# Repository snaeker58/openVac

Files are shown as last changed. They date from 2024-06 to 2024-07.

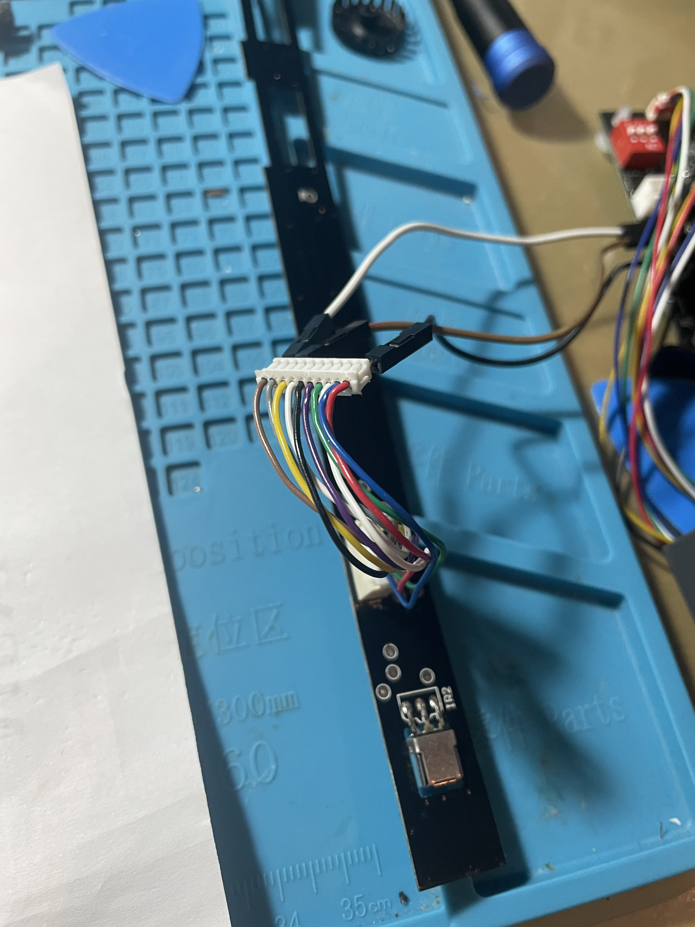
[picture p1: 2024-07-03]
Sessions/v0 Sessions (Sessions 1 - 13)/Session 12/img_build2.jpeg

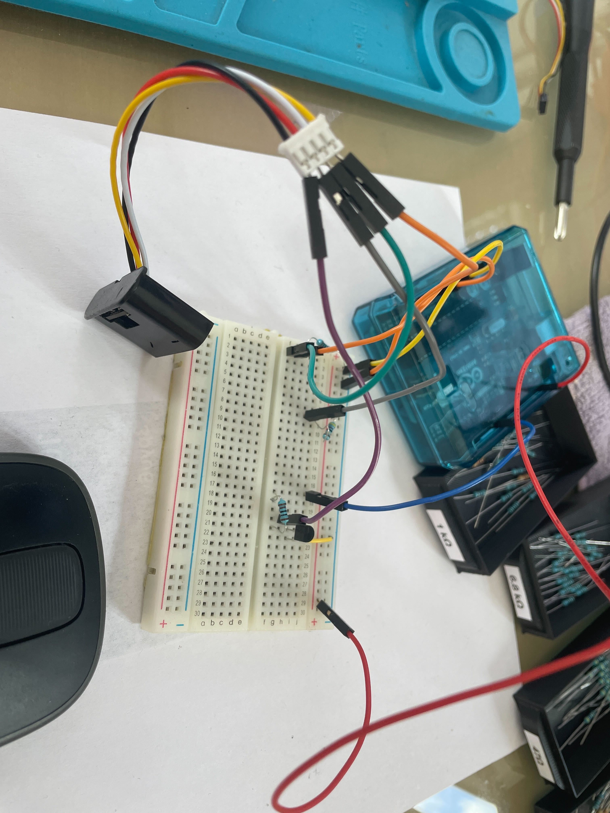
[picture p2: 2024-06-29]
Sessions/v0 Sessions (Sessions 1 - 13)/Session 2/img-build.jpg

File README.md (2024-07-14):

# OpenVac Project

The goal of OpenVac is to create a new open-source control board for my braindead eufy RoboVac 11.

## General Timeline

### Concept v0

#### Finished

##### Motor Drive Circuit
- motor driver / H-bridge design

##### Brush Control
- drive circuits for all cleaning brushes

##### Vacuum
- understanding pinout

##### Basic Sensing
- understanding the various sensors
- reverse engineering the main sensor array
- make edge sensors functional
  
---

### Movement Phase v0.1

#### In Progress

##### Basic Movement
- steering and acceleration

##### Movement PCB
- motor drive circuit
- side brush control circuit
- main brush control circuit
- PWM vacuum 
  
---
### Future Phases...

#### Further Down the Line

##### Determine Microprocessor
- Based on GPIO and analog as well as performance requirements

##### Integrate Microprocessor
- Hardware integration of all support circuits required by the microprocessor and connection to all previous systems

#### Far Future

##### Navigational Software
- Software to allow autonomous cleaning

##### User Interface
- Interface to allow more precise control

### Estimated Time
2 years to infinity

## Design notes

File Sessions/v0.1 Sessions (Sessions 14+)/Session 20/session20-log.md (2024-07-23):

# Building an Open Source Robot Vacuum Based on the Eufy RoboVac 11 - Session 20

### Progress Update

- **Cost Optimization**
  - Modified the board to fit within a 100mm by 100mm space
  - Applied for a $100 PCB production grant to finance PCBs across all phases
  - Reduced the board cost from €40 to €4

### Next Steps

- **Grant Utilization**
  - Plan to use the grant to finance the production of PCBs in all phases

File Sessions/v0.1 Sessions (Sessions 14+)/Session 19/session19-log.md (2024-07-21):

# Building an Open Source Robot Vacuum Based on the Eufy RoboVac 11 - Session 19

### Progress Update

- **Board Completion**
  - Finished the PCB design
  - Design Rule Check (DRC) completed successfully
  - Current board cost is €44 due to its size

### Next Steps

- **Cost Optimization**
  - Create a second, cost-optimized version of the PCB in the next session

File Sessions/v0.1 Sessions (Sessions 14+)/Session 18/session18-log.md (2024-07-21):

# Building an Open Source Robot Vacuum Based on the Eufy RoboVac 11 - Session 18

### Progress Update

- **Component Placement and Routing**
  - Placed all components in their designated spots on the board
  - Began the routing process

### Next Steps

- **Board Completion and Verification**
  - Finish routing the board
  - Conduct final verification before ordering the PCB

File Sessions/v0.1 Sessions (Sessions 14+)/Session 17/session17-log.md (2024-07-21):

# Building an Open Source Robot Vacuum Based on the Eufy RoboVac 11 - Session 17

### Progress Update

- **Motor Drive Transfer**
  - Transferred the motor drive to the schematic and PCB
  - Began working on the PCB layout

### Next Steps

- **Layout Completion**
  - Continue and complete the PCB layout in the next session

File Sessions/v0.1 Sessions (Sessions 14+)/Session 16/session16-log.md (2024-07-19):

# Building an Open Source Robot Vacuum Based on the Eufy RoboVac 11 - Session 16

### Progress Update

- **Motor Encoder Success**
  - Repeated previous attempts to integrate the motor encoder, achieving successful operation
  - Determined the gearing ratio from encoder to wheel is either 1:40 or 1:44

### Next Steps

- **Board Transfer and Finalization**
  - Transfer the working motor encoder setup to the PCB
  - Begin finalizing the board design in the next session

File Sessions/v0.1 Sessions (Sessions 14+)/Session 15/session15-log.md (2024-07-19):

# Building an Open Source Robot Vacuum Based on the Eufy RoboVac 11 - Session 15

### Progress Update

- **Vacuum Transfer and PWM Testing**
  - Transferred the vacuum system to the new setup
  - Spent significant time testing the PWM to ensure proper functionality
  - Encountered and addressed some strange behavior when changing the PWM signal

- **Cable Modification**
  - Modified the cable to fit JST Ph connectors
  - Noted that these connectors may need upgrading due to the close Amp limits for JST Phs

### Next Steps

- **Wheel Encoders**
  - Tackle the integration of wheel encoders, anticipating potential difficulties
  - Prepare for the possibility of replacing wheel encoders with hall effect sensors if necessary

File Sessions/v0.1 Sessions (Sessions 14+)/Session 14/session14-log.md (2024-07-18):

# Building an Open Source Robot Vacuum Based on the Eufy RoboVac 11 - Session 14

### Progress Update

- **First Viable PCB Design**
  - Started working on the first viable PCB design
  - The design is simple, including only necessary components for easy testing with an Arduino Uno
  - Transferred all brush motor controls to the new PCB design
  - Spent considerable time matching the holes and odd shape of the original PCB to ensure the new one fits as a drop-in replacement

### Next Steps

- **PCB Design Finalization**
  - Finalize the PCB design, ensuring all necessary components and fittings are accurate
  - Prepare for initial testing with the Arduino Uno once the PCB is ready

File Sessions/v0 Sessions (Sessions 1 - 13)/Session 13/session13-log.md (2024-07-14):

# Building an Open Source Robot Vacuum Based on the Eufy RoboVac 11 - Session 13

### Progress Update

- **Bumper Array Transfer**
  - Transferred the bumper array schematics to the KiCad project

- **Development Process Restructure**
  - Restructured the development process from phase v0 to v0.1
  - This restructuring does not include a specific hardware or software milestone
  - Most previous work remains intact

### Next Steps

- **Motor Encoders**
  - Implement motor encoders to enable non-autonomous movement in the next session

- **No-Sensor PCB Prototype**
  - Create the first no-sensor PCB prototype to test movement following the implementation of motor encoders

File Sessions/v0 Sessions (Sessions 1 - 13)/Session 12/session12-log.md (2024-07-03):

# Building an Open Source Robot Vacuum Based on the Eufy RoboVac 11 - Session 13

### Progress Update

- **Functionality Testing**
  - Decided to test the functionality of the main sensor array instead of transferring schematics to KiCad
  - Verified the accuracy of the hand-drawn schematic
  - Encountered confusion regarding the original robot's implementation
  - Powered the IR LEDs from the 12V rail

### Next Steps

- **Main Sensor Array in KiCad**
  - Add the main sensor array to KiCad in upcoming sessions
- **Infrared Sensing Code**
  - Modify and write code for infrared sensing
- **Research**
  - Conduct research into pulsed IR distance sensing

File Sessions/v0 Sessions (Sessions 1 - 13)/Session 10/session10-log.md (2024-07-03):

# Building an Open Source Robot Vacuum Based on the Eufy RoboVac 11 - Session 10

### Progress Update

- **Reverse Engineering Sensors**
  - Spent the session reverse engineering the main sensors in the bumper bar
  - Understood the actual bumpers (which are also IR) and the side IR sensor
  - Encountered a complex IR LED array in the main bumper bar with components labeled Q? resembling transistors, LEDs, or receivers
  - Progress was slow due to time spent removing foam from the PCB

### Next Steps

- **Clarifying Sensor Components**
  - Continue investigating the components in the main bumper bar
  - Aim to clear up confusion regarding the Q-labeled components in the next session

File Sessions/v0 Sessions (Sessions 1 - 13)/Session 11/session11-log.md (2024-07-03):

# Building an Open Source Robot Vacuum Based on the Eufy RoboVac 11 - Session 11

### Progress Update

- **Main Sensor Array Schematics**
  - Created the first schematics of the main sensor array
  - Identified two LED arrays and three possible SMD sensor arrays
  - Also identified two larger sensor arrays

### Next Steps

- **KiCad File Transfer**
  - Transfer the schematics to a KiCad file in the next session

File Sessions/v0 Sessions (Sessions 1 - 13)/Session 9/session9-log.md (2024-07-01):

# Building an Open Source Robot Vacuum Based on the Eufy RoboVac 11 - Session 9

### Progress Update

- **Cleaning Brushes Motors**
  - Finished wiring up all the remaining cleaning brushes motors
  - Wiring was straightforward and simple

- **PWM Fan**
  - PWM fan was already pinned out and includes its own PWM controller
  - Only requires a PWM signal for operation
  - Plan to write the prototype code for the PWM fan in the next session

### Next Steps

- **Major Sensing System**
  - With the PWM fan prototype code pending, the major sensing system is the last component to address before completing the first prototype hardware revision

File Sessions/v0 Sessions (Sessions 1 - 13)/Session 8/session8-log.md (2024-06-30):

# Building an Open Source Robot Vacuum Based on the Eufy RoboVac 11 - Session 8
### Progress Update

- **Prototype Sketch**
  - Wrote a prototype sketch that worked successfully
  - Leveraged knowledge of writing libraries, avoiding the need for refactoring
  - Writing and implementing the library in a simpler sketch was seamless

- **EdgeSens Library Revision**
  - Revised the EdgeSens library
  - Removed unnecessary serial begin in the library implementation

### Next Steps

- **Testing with Actual Motors**
  - Awaiting orders to arrive for testing with the actual motors
- **Circuit Design**
  - Continue designing circuits for the brushes, which shouldn't be too difficult

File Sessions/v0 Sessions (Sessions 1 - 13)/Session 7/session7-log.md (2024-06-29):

# Building an Open Source Robot Vacuum Based on the Eufy RoboVac 11 - Session 7

### Progress Update

- **H-Bridge Development**
  - Built the "final" H-Bridge
  - Found a few issues with MOSFETs orientation in the schematics
  - The build took most of the hour, resulting in little progress otherwise

- **Next Steps**
  - Now that the build works, I can start writing the code to digitally control it

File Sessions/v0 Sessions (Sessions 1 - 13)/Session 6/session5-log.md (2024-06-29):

# Building an Open Source Robot Vacuum Based on the Eufy RoboVac 11 - Session 6

### Progress Update

- This session, I could finally test my written library
  - Required a few minor fixes and a `keywords.txt`
  - Now fully working and much simpler in code than the previous prototype setup

- Next Steps
  - Write a prototype to drive the motors through the H-Bridge with the Arduino Uno R3

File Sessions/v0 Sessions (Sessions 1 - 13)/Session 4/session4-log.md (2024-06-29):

# Building an Open Source Robot Vacuum Based on the Eufy RoboVac 11 - Session 4

### Progress Update

- **H-Bridge Motor Driver**
  - Drive circuit is now functional
  - Overhauled the schematic into a proper hierarchical structure

- **Upcoming Tasks**
  - This weekend, drive motor and edge sensor circuits should enter the validation phase
  - After validation, start working on cleaning motors and positional IR sensing
  - Filtering and other non-functional features will likely need to be added

- **Future Plans**
  - After designing and validating all individual circuits, the general architecture of the platform can be determined (e.g., ESP32-S3-Wroom-1U, Arduino Nano 33 IoT)
  - Determining the platform architecture is still far in the future as the requirements are still unclear

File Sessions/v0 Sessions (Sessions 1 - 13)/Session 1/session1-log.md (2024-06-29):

# Building an Open Source Robot Vacuum Based on the Eufy RoboVac 11 - Session 1

### Progress Update

- **Designed First Revision of the H-Bridge for the Main Drive System**
  - Encountered issues with the transistors controlling the P-Channel MOSFETs
  - Breadboard testing seems to have ended in success (TBD if it can be implemented in its current form into the H-Bridge)

- **Main Drive Motors**
  - Successfully pinned our main drive motors
  - Killed encoder sensor in the process, but have replacements on hand

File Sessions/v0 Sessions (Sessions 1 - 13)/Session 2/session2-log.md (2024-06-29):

# Building an Open Source Robot Vacuum Based on the Eufy RoboVac 11 - Session 2

### Progress Update

- **Drive Circuit**
  - Due to pending part orders, the drive circuit had to be put on hold
  - Drive circuit development should continue this week when deliveries arrive

- **Infrared Sensing**
  - Started on the infrared sensing
  - Circuit is complete and tested
  - In the next session, I will work on the code

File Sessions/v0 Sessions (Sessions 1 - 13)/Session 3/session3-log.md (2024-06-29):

# Building an Open Source Robot Vacuum Based on the Eufy RoboVac 11 - Session 3

### Progress Update

- **Code Development / Refinement for the Infrared Sensing Mechanism**
  - Basic code is finished
  - The sensor works and has been set to clamp for an edge sensor application
  - If the robot moves over a ledge, it will trip

- **Next Steps**
  - Convert the code into a library
  - Once the drive system is finished, move all systems to a prototype board and perform a test drive
  - This should enable some real-world testing of the edge sensor mechanism

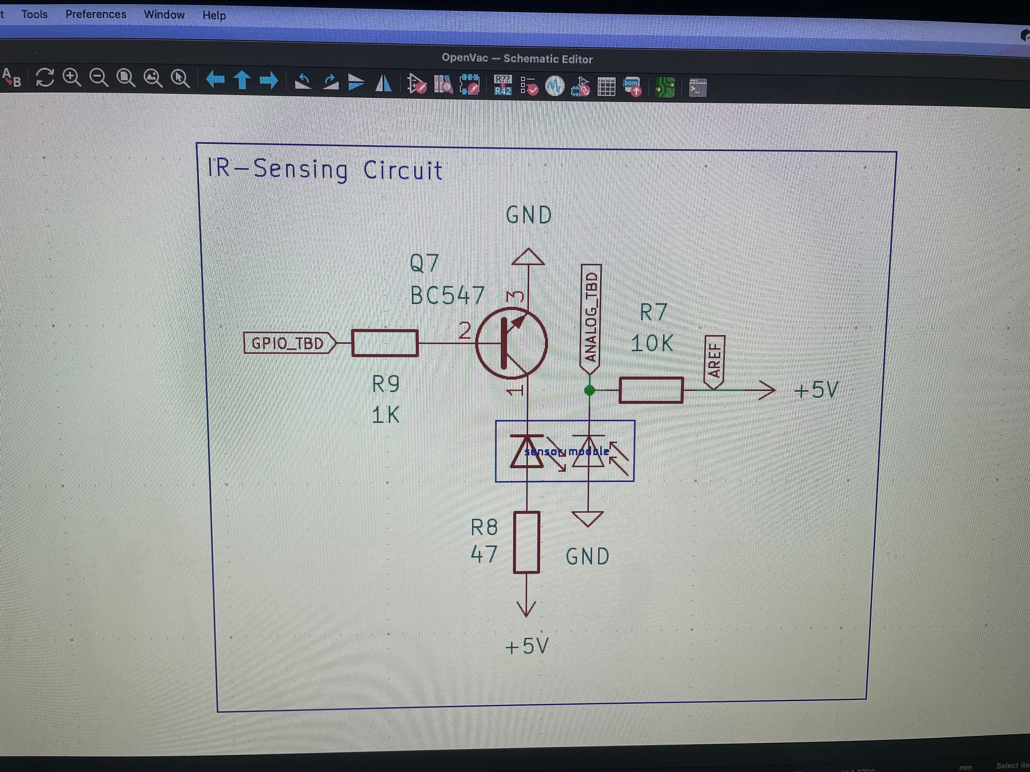
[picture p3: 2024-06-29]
Sessions/v0 Sessions (Sessions 1 - 13)/Session 2/img-schematic.jpg

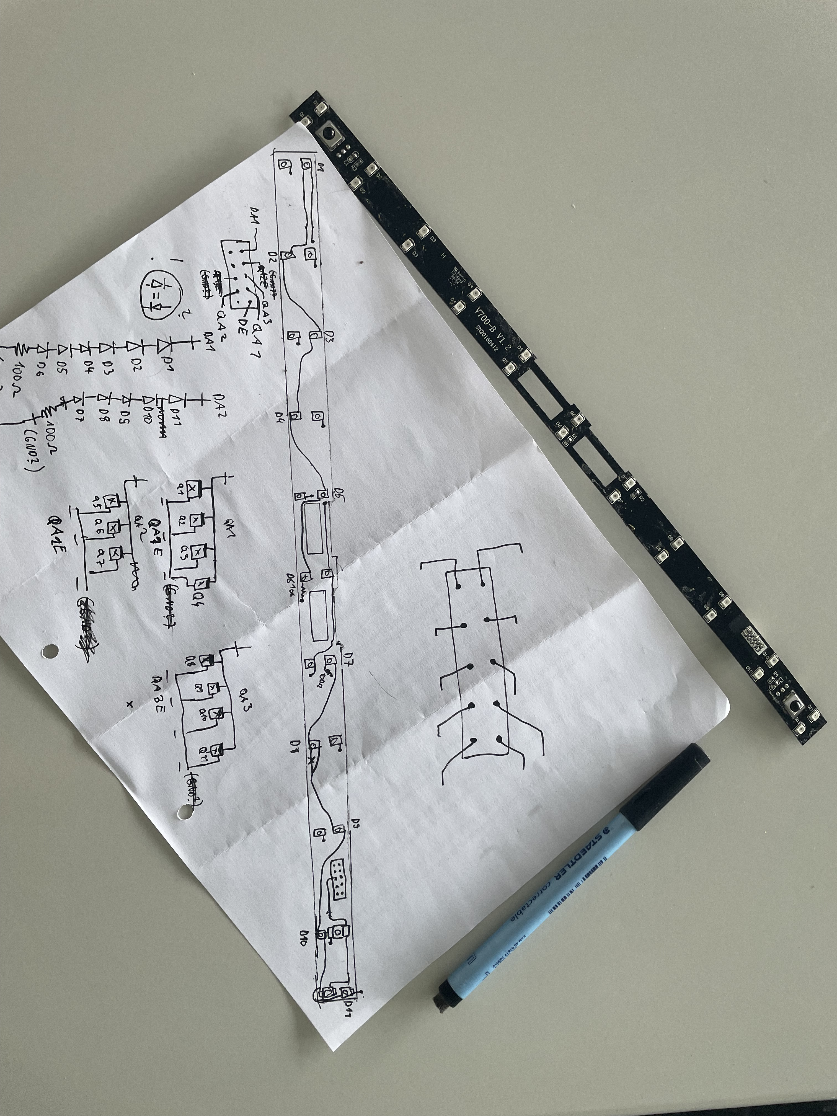
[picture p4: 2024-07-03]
Sessions/v0 Sessions (Sessions 1 - 13)/Session 11/img_schematic.jpeg

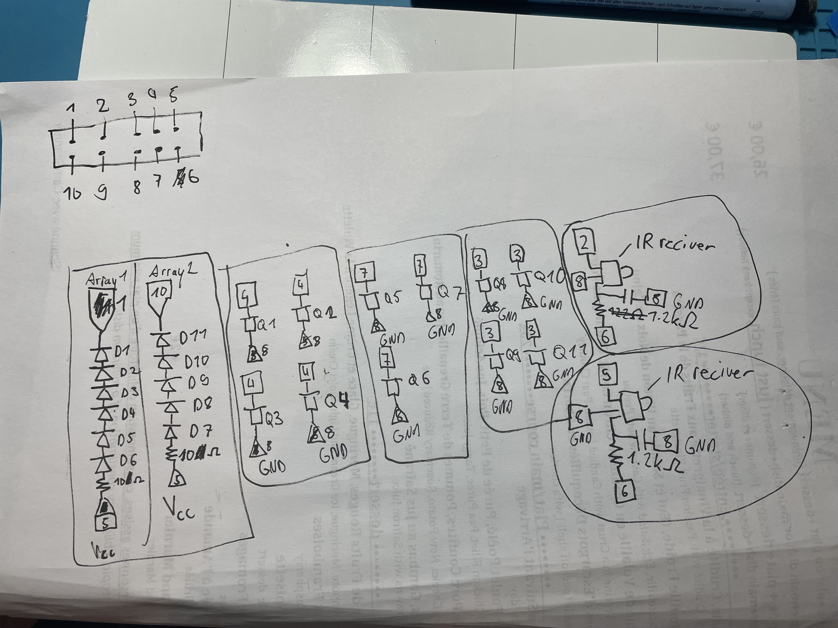
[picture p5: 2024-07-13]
Sessions/v0 Sessions (Sessions 1 - 13)/Session 12/img_schematic.jpeg

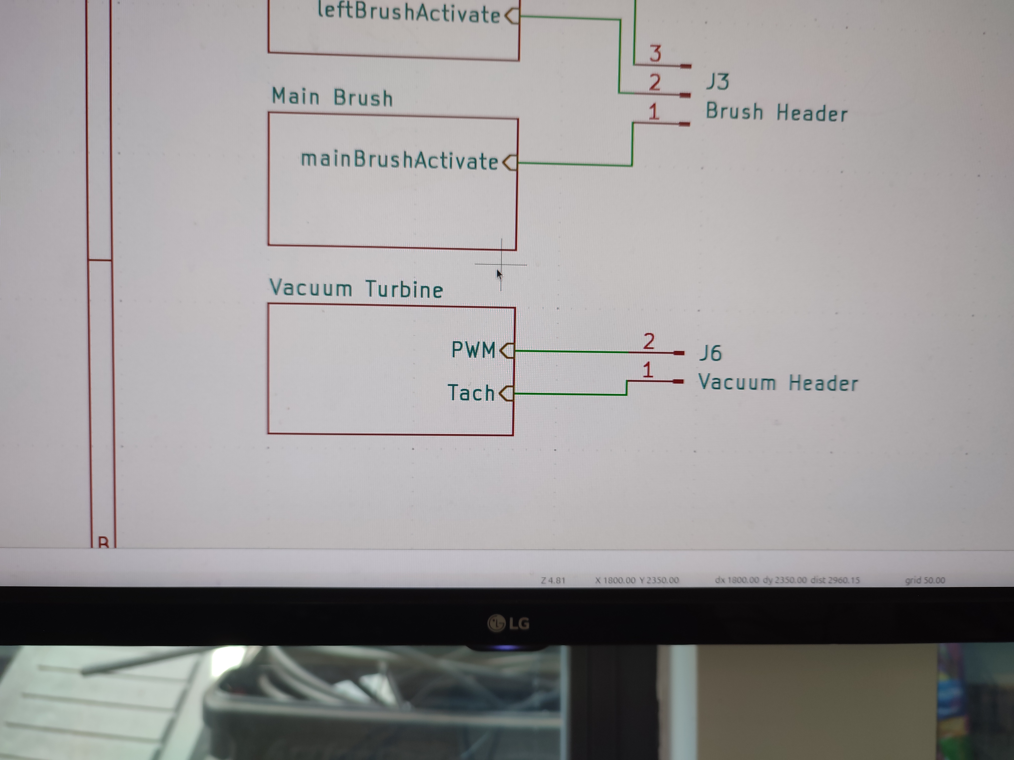
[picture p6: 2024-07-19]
Sessions/v0.1 Sessions (Sessions 14+)/Session 15/img_schematic.jpg

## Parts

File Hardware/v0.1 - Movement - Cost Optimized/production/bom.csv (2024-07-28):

Designator | Footprint | Quantity | Value | LCSC Part #
C1, C2 | CP_Radial_D4.0mm_P1.50mm | 2 | 0.1uF
J1 | JST_PH_B2B-PH-K_1x02_P2.00mm_Vertical | 1 | Brush Motor 2 (right)
J2 | JST_PH_B2B-PH-K_1x02_P2.00mm_Vertical | 1 | Brush Motor 1 (left)
J3 | JST_PH_B3B-PH-K_1x03_P2.00mm_Vertical | 1 | Brush Header (control)
J4 | JST_PH_B2B-PH-K_1x02_P2.00mm_Vertical | 1 | Brush Motor Main
J5 | JST_PH_B4B-PH-K_1x04_P2.00mm_Vertical | 1 | Vacuum
J6 | JST_PH_B2B-PH-K_1x02_P2.00mm_Vertical | 1 | Vacuum Header (control)
J7 | JST_PH_B6B-PH-K_1x06_P2.00mm_Vertical | 1 | Motor (left)
J8 | JST_PH_B6B-PH-K_1x06_P2.00mm_Vertical | 1 | Motor (right)
J9 | JST_PH_B6B-PH-K_1x06_P2.00mm_Vertical | 1 | Motor Header (control)
Q1, Q10, Q12, Q13, Q15, Q2, Q3, Q4, Q6, Q7, Q9 | TO-220-3_Vertical | 11 | IRF540N
Q11, Q14, Q5, Q8 | TO-220-3_Vertical | 4 | IRF9540N
R1, R10, R12, R13, R14, R17, R18, R19, R2, R3, R5, R6, R7, R8, R9 | R_Axial_DIN0207_L6.3mm_D2.5mm_P10.16mm_Horizontal | 15 | 10k
R11, R15 | R_Axial_DIN0207_L6.3mm_D2.5mm_P10.16mm_Horizontal | 2 | 10
R16, R4 | R_Axial_DIN0207_L6.3mm_D2.5mm_P10.16mm_Horizontal | 2 | 5.1k

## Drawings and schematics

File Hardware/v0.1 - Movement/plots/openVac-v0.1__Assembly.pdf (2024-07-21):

A

A

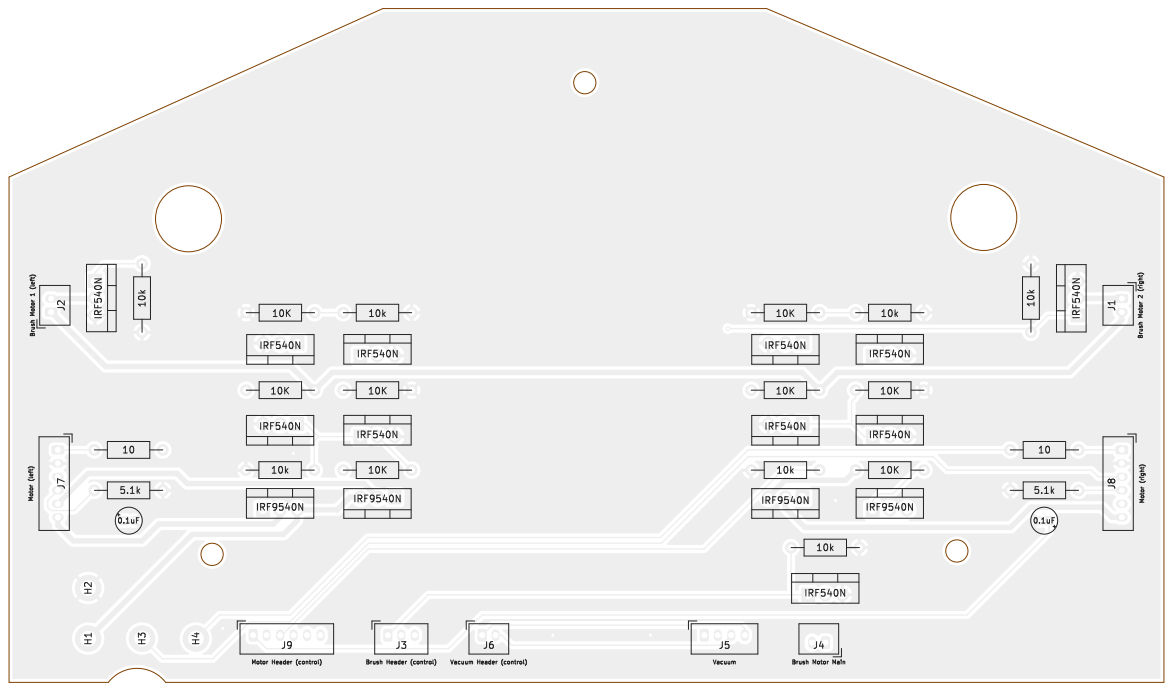
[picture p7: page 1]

Id: 1/1 Title: File: openVac-v0.1.kicad_pcb Sheet:

J6 J7 1 | 2 | 3 | 4 | 5 | 6

A

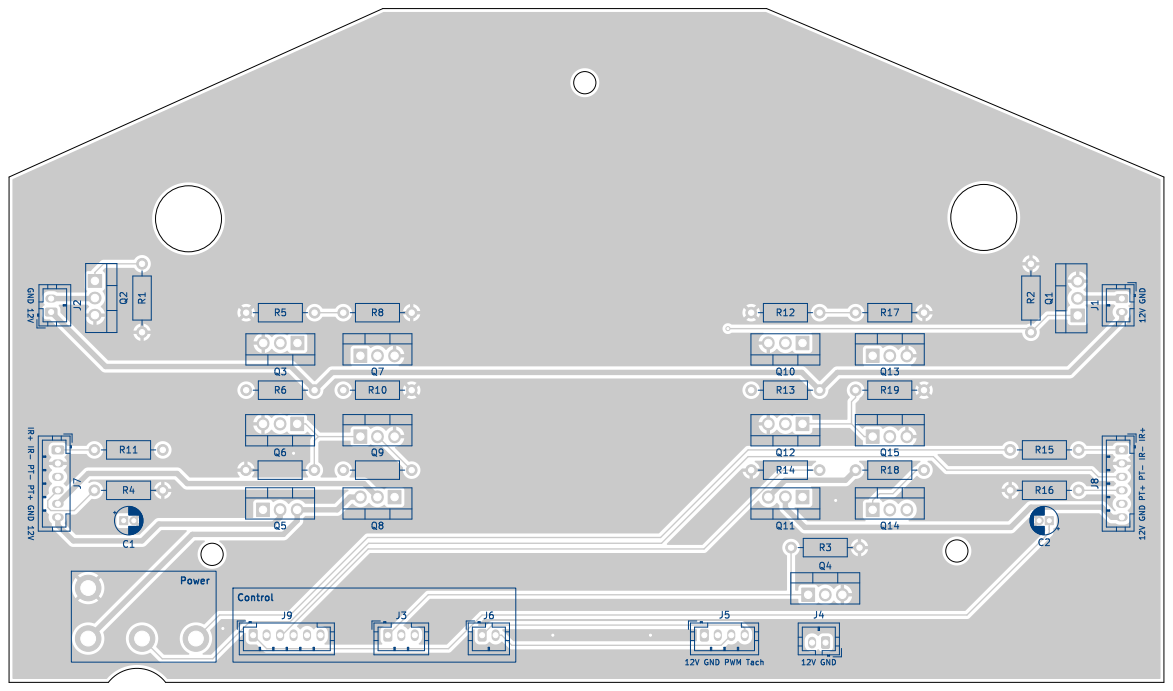
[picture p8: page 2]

12V GNDGND 12V 12V GND PT+ PT- IR- IR+IR+ IR- PT- PT+ GND 12V

Id: 1/1 Title: File: openVac-v0.1.kicad_pcb Sheet:

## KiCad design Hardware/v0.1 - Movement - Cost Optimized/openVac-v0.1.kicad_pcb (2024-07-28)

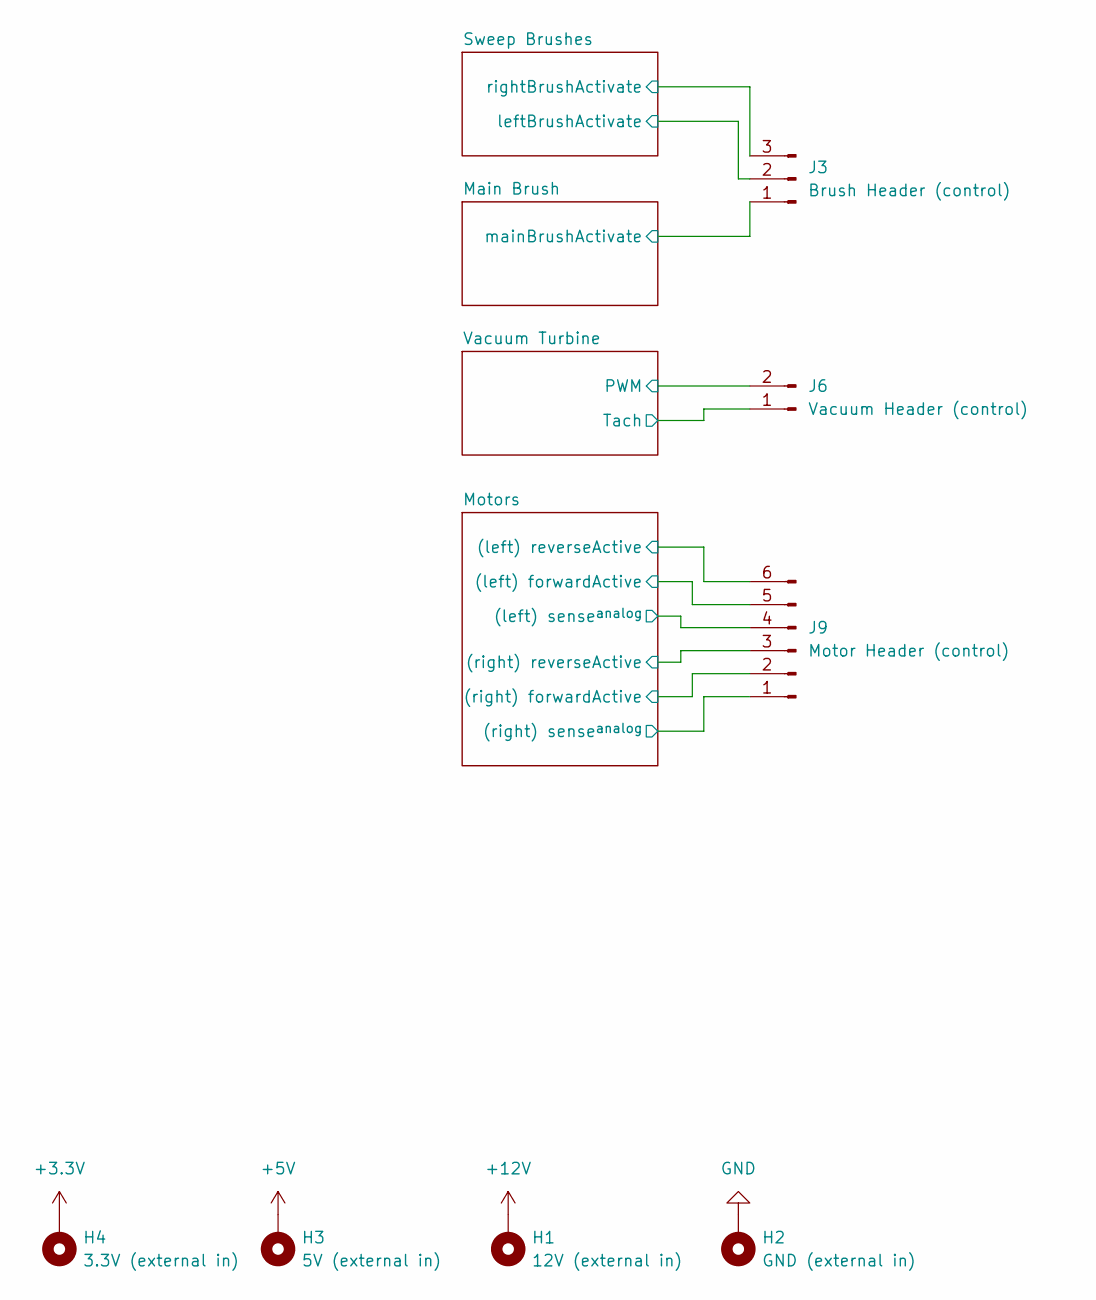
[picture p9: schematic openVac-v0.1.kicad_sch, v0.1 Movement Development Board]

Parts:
H1: 12V (external in); MountingHole_2.2mm_M2_DIN965_Pad
H2: GND (external in); MountingHole_2.2mm_M2_DIN965_Pad
H3: 5V (external in); MountingHole_2.2mm_M2_DIN965_Pad
H4: 3.3V (external in); MountingHole_2.2mm_M2_DIN965_Pad
J3: Brush Header (control); JST_PH_B3B-PH-K_1x03_P2.00mm_Vertical
J6: Vacuum Header (control); JST_PH_B2B-PH-K_1x02_P2.00mm_Vertical
J9: Motor Header (control); JST_PH_B6B-PH-K_1x06_P2.00mm_Vertical

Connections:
+3.3V: H4.1; also elsewhere on the board
+5V: H3.1; also elsewhere on the board
+12V: H1.1; also elsewhere on the board
/Main Brush/mainBrushActivate: J3.1; also elsewhere on the board
/Motors/(left) forwardActive: J9.5; also elsewhere on the board
/Motors/(left) reverseActive: J9.6; also elsewhere on the board
/Motors/(left) sense^{analog}: J9.4; also elsewhere on the board
/Motors/(right) forwardActive: J9.2; also elsewhere on the board
/Motors/(right) reverseActive: J9.3; also elsewhere on the board
/Motors/(right) sense^{analog}: J9.1; also elsewhere on the board
/Sweep Brushes/leftBrushActivate: J3.2; also elsewhere on the board
/Sweep Brushes/rightBrushActivate: J3.3; also elsewhere on the board
/Vacuum Turbine/PWM: J6.2; also elsewhere on the board
/Vacuum Turbine/Tach: J6.1; also elsewhere on the board
GND: H2.1; also elsewhere on the board

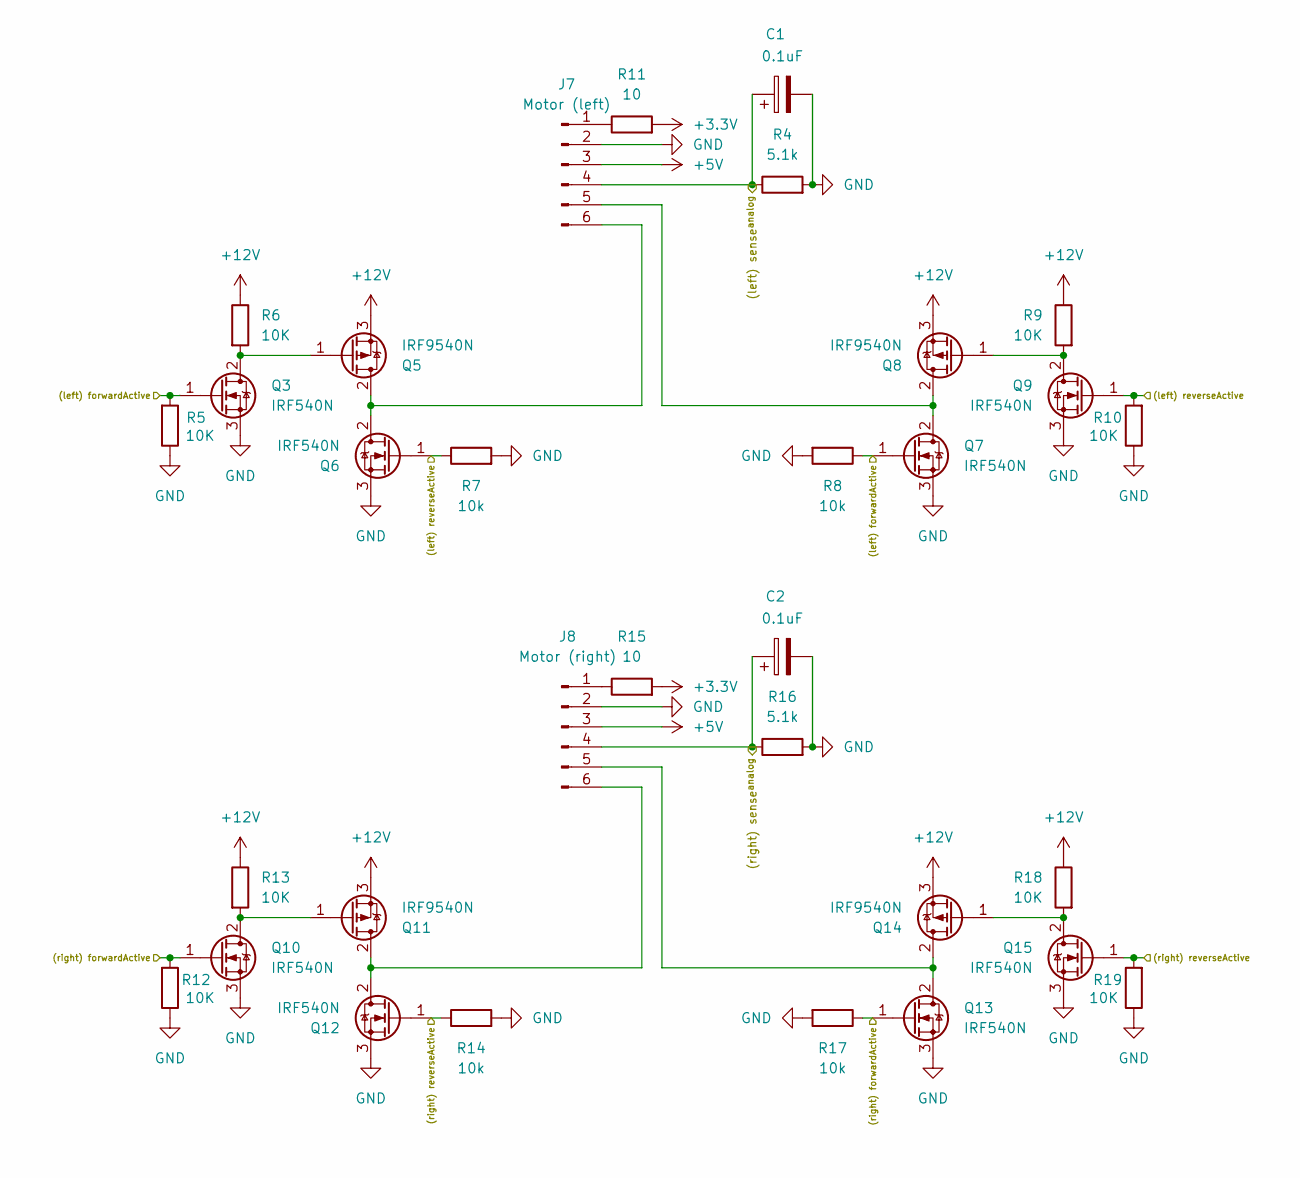
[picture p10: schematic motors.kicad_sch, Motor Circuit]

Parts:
C1, C2: 0.1uF; CP_Radial_D4.0mm_P1.50mm
J7: Motor (left); JST_PH_B6B-PH-K_1x06_P2.00mm_Vertical
J8: Motor (right); JST_PH_B6B-PH-K_1x06_P2.00mm_Vertical
Q3, Q6, Q7, Q9, Q10, Q12, Q13, Q15: IRF540N; TO-220-3_Vertical
Q5, Q8, Q11, Q14: IRF9540N; TO-220-3_Vertical
R4, R16: 5.1k; R_Axial_DIN0207_L6.3mm_D2.5mm_P10.16mm_Horizontal
R5, R6, R9, R10, R12, R13, R18, R19: 10K; R_Axial_DIN0207_L6.3mm_D2.5mm_P10.16mm_Horizontal
R7, R8, R14, R17: 10k; R_Axial_DIN0207_L6.3mm_D2.5mm_P10.16mm_Horizontal
R11, R15: 10; R_Axial_DIN0207_L6.3mm_D2.5mm_P10.16mm_Horizontal

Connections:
+3.3V: R11.2, R15.2; also elsewhere on the board
+5V: J7.3, J8.3; also elsewhere on the board
+12V: Q5.3 (S), Q8.3 (S), Q11.3 (S), Q14.3 (S), R6.1, R9.1, R13.1, R18.1; also elsewhere on the board
/Motors/(left) forwardActive: Q3.1 (G), Q7.1 (G), R5.2, R8.1; also elsewhere on the board
/Motors/(left) reverseActive: Q6.1 (G), Q9.1 (G), R7.1, R10.2; also elsewhere on the board
/Motors/(left) sense^{analog}: C1.1, J7.4, R4.1; also elsewhere on the board
/Motors/(right) forwardActive: Q10.1 (G), Q13.1 (G), R12.2, R17.1; also elsewhere on the board
/Motors/(right) reverseActive: Q12.1 (G), Q15.1 (G), R14.1, R19.2; also elsewhere on the board
/Motors/(right) sense^{analog}: C2.1, J8.4, R16.1; also elsewhere on the board
GND: C1.2, C2.2, J7.2, J8.2, Q3.3 (S), Q6.3 (S), Q7.3 (S), Q9.3 (S), Q10.3 (S), Q12.3 (S), Q13.3 (S), Q15.3 (S), R4.2, R5.1, R7.2, R8.2, R10.1, R12.1, R14.2, R16.2, R17.2, R19.1; also elsewhere on the board
unnamed: J7.1, R11.1
unnamed: J7.5, Q7.2 (D), Q8.2 (D)
unnamed: J7.6, Q5.2 (D), Q6.2 (D)
unnamed: J8.1, R15.1
unnamed: J8.5, Q13.2 (D), Q14.2 (D)
unnamed: J8.6, Q11.2 (D), Q12.2 (D)
unnamed: Q3.2 (D), Q5.1 (G), R6.2
unnamed: Q8.1 (G), Q9.2 (D), R9.2
unnamed: Q10.2 (D), Q11.1 (G), R13.2
unnamed: Q14.1 (G), Q15.2 (D), R18.2

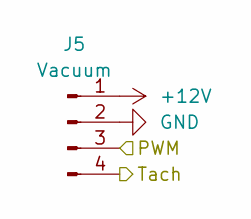
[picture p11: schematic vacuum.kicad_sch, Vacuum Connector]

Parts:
J5: Vacuum; JST_PH_B4B-PH-K_1x04_P2.00mm_Vertical

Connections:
+12V: J5.1; also elsewhere on the board
/Vacuum Turbine/PWM: J5.3; also elsewhere on the board
/Vacuum Turbine/Tach: J5.4; also elsewhere on the board
GND: J5.2; also elsewhere on the board

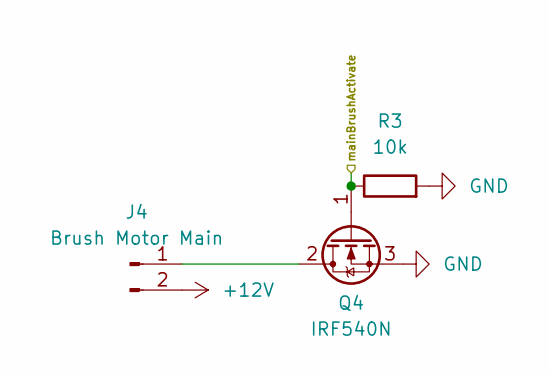
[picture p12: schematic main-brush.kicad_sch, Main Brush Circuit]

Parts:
J4: Brush Motor Main; JST_PH_B2B-PH-K_1x02_P2.00mm_Vertical
Q4: IRF540N; TO-220-3_Vertical
R3: 10k; R_Axial_DIN0207_L6.3mm_D2.5mm_P10.16mm_Horizontal

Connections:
+12V: J4.2; also elsewhere on the board
/Main Brush/mainBrushActivate: Q4.1 (G), R3.1; also elsewhere on the board
GND: Q4.3 (S), R3.2; also elsewhere on the board
unnamed: J4.1, Q4.2 (D)

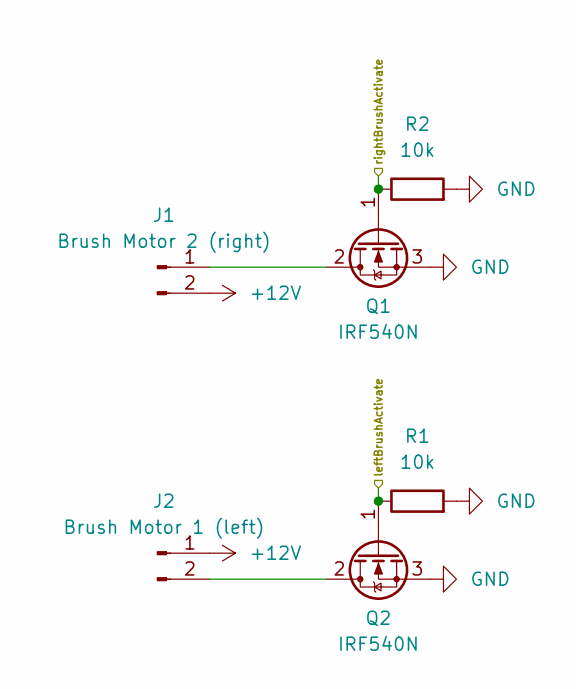
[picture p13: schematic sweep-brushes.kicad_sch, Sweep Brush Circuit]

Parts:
J1: Brush Motor 2 (right); JST_PH_B2B-PH-K_1x02_P2.00mm_Vertical
J2: Brush Motor 1 (left); JST_PH_B2B-PH-K_1x02_P2.00mm_Vertical
Q1, Q2: IRF540N; TO-220-3_Vertical
R1, R2: 10k; R_Axial_DIN0207_L6.3mm_D2.5mm_P10.16mm_Horizontal

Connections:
+12V: J1.2, J2.1; also elsewhere on the board
/Sweep Brushes/leftBrushActivate: Q2.1 (G), R1.1; also elsewhere on the board
/Sweep Brushes/rightBrushActivate: Q1.1 (G), R2.1; also elsewhere on the board
GND: Q1.3 (S), Q2.3 (S), R1.2, R2.2; also elsewhere on the board
unnamed: J1.1, Q1.2 (D)
unnamed: J2.2, Q2.2 (D)

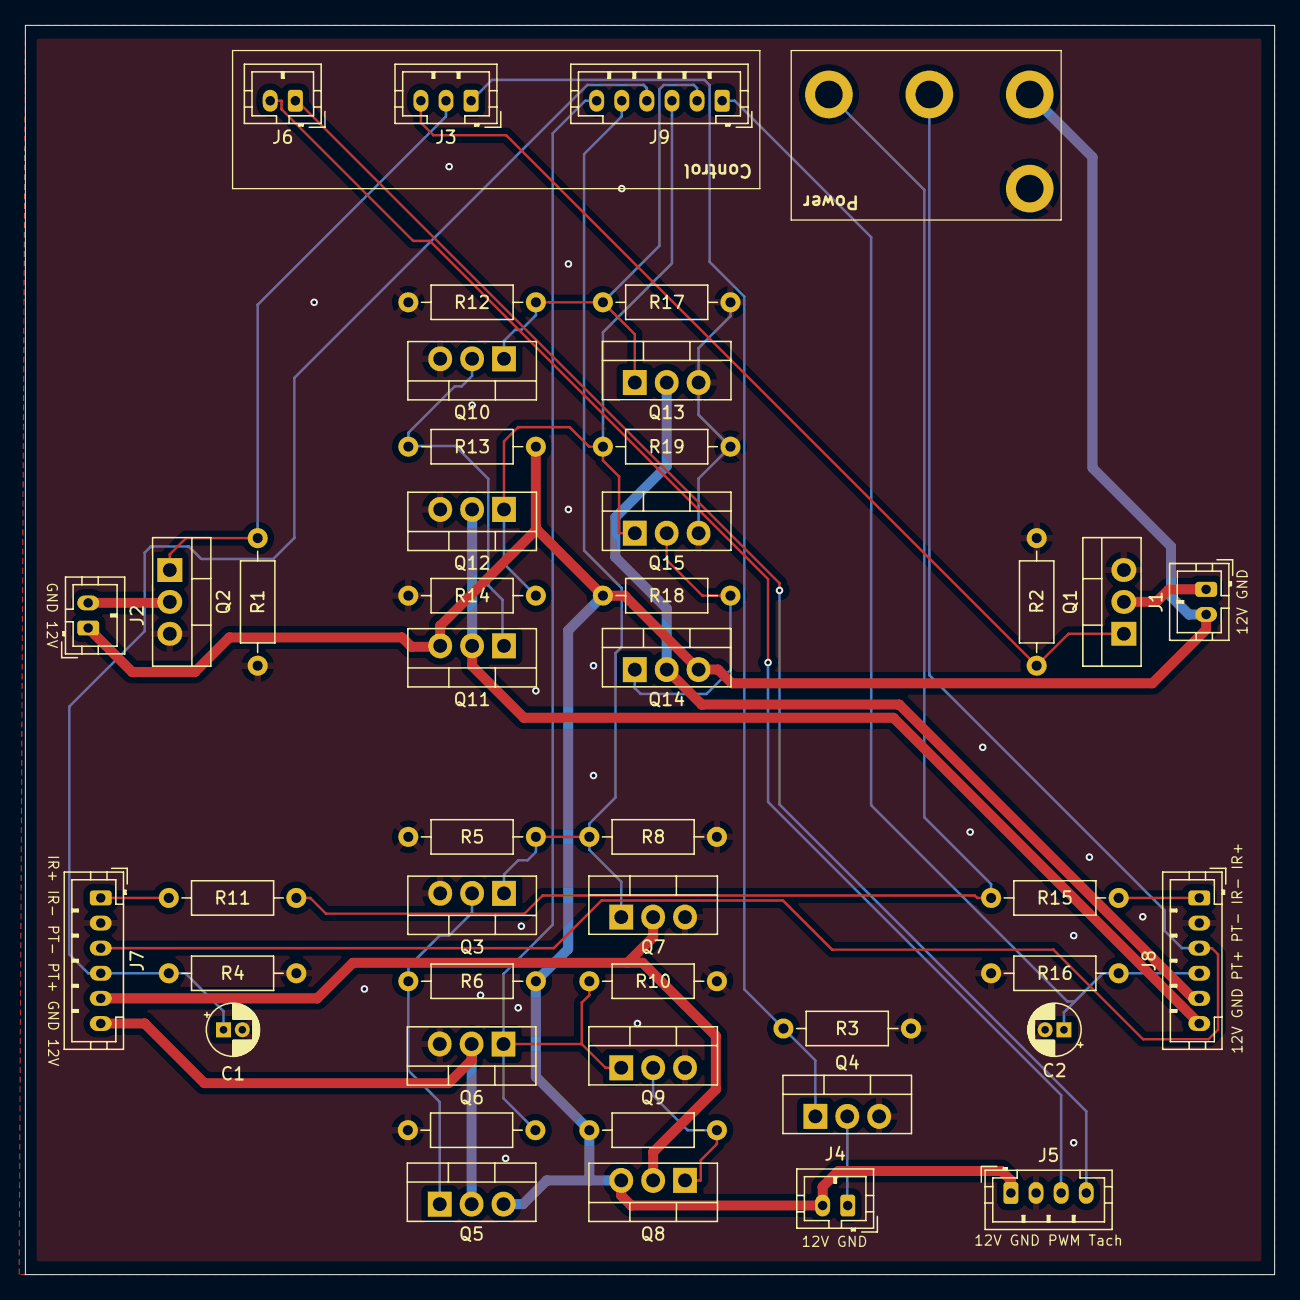
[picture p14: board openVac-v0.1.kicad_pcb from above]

Board: 2 copper layers, 99.5 x 99.5 mm, 49 parts (0 on the bottom side), 28 nets.

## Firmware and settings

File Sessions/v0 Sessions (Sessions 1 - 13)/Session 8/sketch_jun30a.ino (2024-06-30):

#include <MotorDrive.h>

const int drivePin1 = 2;
const int drivePin2 = 3;
MotorDrive motor(drivePin1, drivePin2);

void setup() {
  for (int i = 0; i < 20; i++) {
      motor.forward();
    delay(100);
    motor.backward();
    delay(100);
    motor.forward();
    delay(100);
    motor.backward();
    delay(100);
    }
    motor.stop();
}

void loop() {}

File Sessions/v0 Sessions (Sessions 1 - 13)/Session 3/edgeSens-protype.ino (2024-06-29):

const int irControlPin =  5;  
const int irReceiverPin = A0;
unsigned long ambientSignal, activeSignal; 
unsigned int proximity;
unsigned int normalizedProximity;
bool edgeTrip;

void setup()   {
  Serial.begin(9600);
  analogReference(EXTERNAL);
  pinMode(irControlPin, OUTPUT);
}

void loop(){
  edgeTrip = false;
  ambientSignal = 0;
  activeSignal = 0;
  
  for(int i=0; i<25; i++){
    ambientSignal += analogRead(irReceiverPin);
    delayMicroseconds(500);
  }
  ambientSignal /= 25;

  digitalWrite(irControlPin, HIGH);
  for(int i=0; i<25; i++){
    activeSignal += analogRead(irReceiverPin);
    delayMicroseconds(500);
  }
  activeSignal /= 50;
  
  proximity = ambientSignal - activeSignal;
  normalizedProximity = constrain(proximity, 600, 900);
  if (normalizedProximity == 600) {
    edgeTrip = true;
  }
  Serial.println(edgeTrip);

  digitalWrite(irControlPin,LOW);
}

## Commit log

2024-06-29 Circuit designs
    [OpenVac.kicad_pcb, OpenVac.kicad_sch, edge-sens-interface-circuit.kicad_sch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]
2024-06-29 Documentation of the development process
    [OpenVac.kicad_sch, edge-sens-interface-circuit.kicad_sch, ir-sens-module.kicad_sch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]
2024-06-29 Additional session, fixed typo in session 4
    [EdgeSens.cpp]
2024-06-29 Fixed schematic mistake
    [OpenVac.kicad_pcb, OpenVac.kicad_sch, motor-drive-circuit.kicad_sch]
2024-06-29 Added folder for better structure
    [OpenVac.kicad_pcb, OpenVac.kicad_sch, edge-sens-interface-circuit.kicad_sch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]
2024-06-29 fix: mosfet orientation
    [OpenVac.kicad_sch, motor-drive-circuit.kicad_sch]
2024-07-01 Added new session
    [OpenVac.kicad_pcb, OpenVac.kicad_sch, edge-sens-interface-circuit.kicad_sch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]
2024-07-01 feat: all motors and main turbine wired in
    [OpenVac.kicad_sch, front-brush-motor-circuit.kicad_sch, turbine-motor-circuit.kicad_sch]
2024-07-13 Session 13 hardware modifications
    [OpenVac.kicad_sch, bumper-array-interface-circuit.kicad_sch, bumper-array.kicad_sch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]
2024-07-13 Device resync (ignore)
2024-07-14 Phase v0.1 restructure
    This marks the end of the concept phase from now on every phase is supposed to be finalized with a prototype PCB. Each phase focusing on a specific aspect of the robot.
    [OpenVac.kicad_pcb, OpenVac.kicad_sch, bumper-array-interface-circuit.kicad_sch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]
2024-07-18 Added session 14
    [main-brush.kicad_sch, openVac-v0.1.kicad_pcb, openVac-v0.1.kicad_sch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]
2024-07-19 added session 15
    [main-brush.kicad_sch, openVac-v0.1.kicad_pcb, openVac-v0.1.kicad_sch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]
2024-07-20 Github Desktop Backup
    [openVac-v0.1.kicad_pcb, openVac-v0.1.kicad_sch, untitled.kicad_sch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]
2024-07-21 added session 17
    [main-brush.kicad_sch, openVac-v0.1.kicad_pcb, openVac-v0.1.kicad_sch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]
2024-07-21 added session 18
    [openVac-v0.1.kicad_pcb]
2024-07-21 added session 19
    [openVac-v0.1.kicad_pcb]
2024-07-23 added session 20
    [main-brush.kicad_sch, motors.kicad_sch, openVac-v0.1.kicad_pcb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]
2024-07-28 Fix: Missing soldermask
    [Battery-IC-Interposer.kicad_pcb, Battery-IC-Interposer.kicad_sch, bom.csv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]
